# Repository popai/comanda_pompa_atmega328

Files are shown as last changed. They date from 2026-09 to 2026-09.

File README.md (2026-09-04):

# comanda_pompa — controler de umplere bazin

Firmware pentru o placă custom cu **ATmega328PU la 16 MHz** care umple automat un
bazin: comandă releul unei pompe în funcție de nivelul citit cu un senzor
ultrasonic pe RS485 și afișează gradul de umplere pe un bargraph de 7 LED-uri.

Senzorul (**A0121A4**, Modbus RTU) este montat deasupra bazinului și privește în
jos, deci distanța măsurată **scade** pe măsură ce bazinul se umple.

## Logica de funcționare

| Condiție | Acțiune |
|---|---|
| Nivel ≤ 50% (bazin gol sau sub jumătate) | Pornește pompa |
| Nivel ≥ 95% (bazin plin) | Oprește pompa |
| Între 50% și 95% | Păstrează starea curentă |

Banda 50%…95% **este** histerezisul: odată pornită, pompa merge până la plin,
deci nu poate clipi în jurul niciunui prag. Peste asta, un filtru median pe 3
citiri și confirmarea pe 3 citiri consecutive împiedică o singură valoare
aberantă (val, reflexie parazită) să comande releul.

### Protecții

- **Timp maxim de umplere** — 5 de minute de funcționare continuă fără să se
  atingă „plin" înseamnă puț secat, vană închisă sau senzor blocat pe o valoare.
  Pompa se oprește și intră în `AVARIE_TIMP`, stare **cu reținere**: iese doar la
  reset, pentru că repornirea automată ar ține pompa în gol la nesfârșit.
- **Senzor defect** — 5 citiri eșuate consecutive (fără răspuns, CRC greșit, în
  afara plajei) opresc pompa preventiv și trec în `AVARIE_SENZOR`. Starea se
  auto-repară după 3 citiri valide consecutive.
- Releul **nu pornește niciodată** pe baza unei citiri invalide.
- La reset pinul releului este scris `LOW` înainte de `pinMode(OUTPUT)`, ca
  pompa să nu pornească pentru câteva microsecunde la fiecare repornire.
- Watchdog de 8 s, resetat **doar la încheierea unui ciclu de măsurare**, nu la
  fiecare trecere prin `loop()`. Astfel el nu cere doar ca procesorul să fie viu,
  ci ca măsurătorile să avanseze efectiv: dacă bucla s-ar învârti fără să mai
  măsoare (de exemplu cu `millis()` înghețat), watchdog-ul resetează placa și
  pompa se oprește.

## Hardware

### Pinout

| Funcție | Port AVR | Pin Arduino |
|---|---|---|
| LED 1 | PC3 | A3 |
| LED 2 | PC2 | A2 |
| LED 3 | PB5 | 13 |
| LED 4 | PB4 | 12 |
| LED 5 | PB3 | 11 |
| LED 6 | PB2 | 10 |
| LED 7 | PB1 | 9 |
| Releu pompă (activ **HIGH**) | PC4 | A4 |
| RS485 DE + /RE (legate împreună) | PC5 | A5 |
| RS485 RO → RX software | PD5 | 5 |
| RS485 DI ← TX software | PD6 | 6 |

D0/D1 rămân libere pentru upload și pentru logul de debug.
PC4/PC5 sunt și SDA/SCL, dar proiectul nu folosește I2C — fără conflict.

### Senzorul

MAX485 în half-duplex: `DE` și `/RE` sunt legate la același pin, `HIGH` = emisie,
`LOW` = recepție. Firmware-ul ridică linia doar cât durează interogarea.

Comunicația se face pe `SoftwareSerial` la 9600 8N1, protocol Modbus RTU:

- comandă: `01 03 01 01 00 01 D4 36`
- răspuns: 7 octeți — `adresă, funcție, lungime, dataHi, dataLo, crcLo, crcHi`
- valoarea este în zecimi de milimetru; `(dataHi * 256 + dataLo) / 10` = cm
- `dataHi == 0xFF` înseamnă „în afara plajei"

Protocolul, CRC-ul și filtrul de sincronizare sunt preluate neschimbat din
implementarea Zephyr validată pe hardware
(`ncs_app/senzor_umplere/src/dist_sensor.c`). Filtrul aruncă octeți până
întâlnește `0x01` urmat de `0x03`, ceea ce este necesar pentru că la alimentare
senzorul emite un banner text (`APP Run...`) lung exact cât un cadru Modbus.

## Calibrare

**Obligatoriu la montaj.** În [`include/config.h`](include/config.h):

```c
static const uint16_t DIST_PLIN_CM = 20;   // senzor -> suprafața apei, bazin plin
static const uint16_t DIST_GOL_CM  = 150;  // senzor -> fundul bazinului
```

Procedura: montează placa pe bazin, deschide monitorul serial, citește distanța
raportată cu bazinul gol și cu bazinul plin, pune cele două valori aici și
recompilează. Nivelul se calculează liniar între ele, saturat la 0 și 100%.

Restul parametrilor reglabili — praguri, numărul de confirmări, timeout-uri,
timpul maxim de umplere — sunt tot acolo. `config.h` este singurul fișier care
trebuie atins pentru reglaje; în restul codului nu există numere magice.

## Indicații pe LED-uri

**Funcționare normală** — bargraph, LED-urile 1..7 de la nivel mic la nivel mare.
Pragurile sunt așezate la mijlocul fiecărei trepte (≈7, 21, 35, 50, 64, 78, 92%),
cu o zonă moartă de ±2%, ca LED-ul de vârf să nu pâlpâie când nivelul stă exact
pe un prag. Un bazin aproape gol arată „un LED", nu zero — asta distinge vizual
nivelul mic de afișajul stins.

**Avarie** — două tipare imposibil de confundat cu un bargraph real:

| Tipar | Semnificație |
|---|---|
| Toate 7 clipind sincron, 2 Hz | `AVARIE_SENZOR` — senzorul nu răspunde |
| Alternanță 1-3-5-7 / 2-4-6, 1 Hz | `AVARIE_TIMP` — timp maxim depășit, cere reset |

## Compilare și încărcare

Proiect [PlatformIO](https://platformio.org/), env `uno` (ATmega328P la 16 MHz,
bootloader Arduino):

```sh
pio run                 # compilare
pio run -t upload       # încărcare
pio device monitor      # log de debug, 115200 baud
```

Binarul rezultă la `.pio/build/uno/comanda_pompa_uno.hex` — numele este compus
din numele proiectului și al plăcii de către [`extra_script.py`](extra_script.py).

### Ieșirea pe serial

Câte o linie la fiecare ciclu de măsurare (1 s):

```
=== Controler umplere bazin ===
Plin la 20 cm, gol la 150 cm; pornire sub 50%, oprire peste 95%
98 cm | 40% | OPRITA
97 cm | 40% | OPRITA
96 cm | 41% | PORNITA
--- | senzor: fara raspuns | PORNITA
```

## Structura codului

| Fișier | Rol |
|---|---|
| [`include/config.h`](include/config.h) | Pini, cotele bazinului, praguri, timpi — singurul loc de reglat |
| [`src/dist_sensor.cpp`](src/dist_sensor.cpp) | Driver Modbus RTU pe RS485: CRC, sincronizare cadru, reîncercări |
| [`src/pump.cpp`](src/pump.cpp) | Mașina de stări, filtrul median, comanda releului |
| [`src/leds.cpp`](src/leds.cpp) | Bargraph cu histerezis și tiparele de avarie |
| [`src/main.cpp`](src/main.cpp) | `setup()`/`loop()`, watchdog, conversia distanță → procent |

Bucla principală este non-blocantă (`millis()`, fără `delay()`), cu excepția
ciclului de măsurare: cel mult 3 × 550 ms, iar în cazul bun răspunsul vine în
~100 ms.

## Punere în funcțiune

1. `pio run` — compilare curată, fără warning-uri.
2. Alimentează placa **fără senzor conectat** și urmărește monitorul: după 5
   citiri eșuate trebuie să intre în `AVARIE_SENZOR`, cu releul oprit și toate
   LED-urile clipind. Confirmă protecția de senzor defect.
3. Conectează senzorul pe masă, apropie și depărtează o placă plană și verifică
   în log că distanța corespunde realității și că bargraph-ul urcă și coboară.
4. Verifică tranzițiile: releul anclanșează sub 50%, declanșează la 95% și **nu**
   comută între aceste valori.
5. Pentru testul de timp maxim, coboară temporar `MAX_TIMP_UMPLERE_MS` la 30 s,
   ține nivelul sub 50% și confirmă trecerea în `AVARIE_TIMP`.
6. Montează pe bazin, calibrează cele două cote și urmărește un ciclu complet de
   umplere.

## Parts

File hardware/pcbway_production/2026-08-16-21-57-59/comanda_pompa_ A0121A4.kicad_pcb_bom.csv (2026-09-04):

Designator | Quantity | Value | Footprint | Package | MPN | DNP | Mount_Type | Description | KiLib_Generator | LCSC Part # | Manufacturer Mfr. Part # | Sim.Device | Sim.Pins
C1 | 1 | 100nF/C0603 | C_Disc_D3.0mm_W1.6mm_P2.50mm |  |  |  | tht | Unpolarized capacitor, small symbol | capacitor/THT/other | C30926 | 0603B104K500NT
C2, C3 | 2 | 22pF | C_Disc_D3.0mm_W1.6mm_P2.50mm |  |  |  | tht | Unpolarized capacitor, small symbol | capacitor/THT/other
D10 | 1 | RB151 | Diode_Bridge_Round_D9.0mm |  |  |  | tht | Single-Phase Bridge Rectifier, 35V Vrms, 1.5A If, WOG-like package
D2 | 1 | 1N4148 | D_A-405_P10.16mm_Horizontal |  |  |  | tht | Diode, small symbol | diode/THT |  |  | D | 1=K 2=A
J10 | 1 | RS485_M | PinHeader_1x04_P2.54mm_Vertical |  |  |  | tht | Generic connector, single row, 01x04, script generated (kicad-library-utils/schlib/autogen/connector/) | connector/pin_header_socket
J11, J5 | 2 | NC (test led) | PinHeader_1x01_P2.54mm_Vertical |  |  |  | tht | Generic connector, single row, 01x01, script generated | connector/pin_header_socket
J2 | 1 | 220V IN | PhoenixContact_GMSTBA_2,5_6-G-7,62_1x06_P7.62mm_Horizontal |  |  |  | tht | Generic connector, single row, 01x06, script generated (kicad-library-utils/schlib/autogen/connector/) | connector/PhoenixContact
J6 | 1 | CONSOLA | PinHeader_1x04_P2.54mm_Vertical |  |  |  | tht | Generic connector, single row, 01x04, script generated (kicad-library-utils/schlib/autogen/connector/) | connector/pin_header_socket | C2883761 | X6511WVS-04H-C60D48R2
J7 | 1 | LEDS | PinHeader_1x08_P2.54mm_Vertical |  |  |  | tht | Generic connector, single row, 01x08, script generated (kicad-library-utils/schlib/autogen/connector/) | connector/pin_header_socket
J8 | 1 | LED | PinHeader_1x03_P2.54mm_Vertical |  |  |  | tht | Generic connector, single row, 01x03, script generated (kicad-library-utils/schlib/autogen/connector/) | connector/pin_header_socket
J9 | 1 | RS485_uC | PinHeader_1x04_P2.54mm_Vertical |  |  |  | tht | Generic connector, single row, 01x04, script generated (kicad-library-utils/schlib/autogen/connector/) | connector/pin_header_socket
Q2 | 1 | BD139 | TO-126-3_Vertical |  |  |  | tht | 1.5A Ic, 80V Vce, Low Voltage Transistor, TO-126 | package/TO_SOT/THT |  |  | NPN | 1=E 2=C 3=B
R10, R11, R12, R3, R6, R7, R8, R9 | 8 | 1K | R_Axial_DIN0207_L6.3mm_D2.5mm_P10.16mm_Horizontal |  |  |  | tht | Resistor, small symbol | resistor/THT
R13, R4 | 2 | 360R | R_Axial_DIN0207_L6.3mm_D2.5mm_P10.16mm_Horizontal |  |  |  | tht | Resistor, small symbol | resistor/THT
R14, R15, R5 | 3 | 10K | R_Axial_DIN0207_L6.3mm_D2.5mm_P10.16mm_Horizontal |  |  |  | tht | Resistor, small symbol | resistor/THT
R2 | 1 | 1k | R_Axial_DIN0207_L6.3mm_D2.5mm_P7.62mm_Horizontal |  |  |  | tht | Resistor | resistor/THT
RL1 | 1 | 891WP-1A-C | 891WP-1A-C |  |  |  | tht | Standex Meder UMS reed relay, SPST, Closing Contact
SENZOR_D1 | 1 | SENZOR_D | PinHeader_1x04_P2.54mm_Vertical |  |  |  | tht | Generic connector, single row, 01x04, script generated (kicad-library-utils/schlib/autogen/connector/) | connector/pin_header_socket
T1 | 1 | Transformer_1P_1S | Trafo_10V |  |  |  | tht | Transformer, single primary, single secondary
U1 | 1 | ATmega328P-P | DIP-28_W7.62mm |  |  |  | tht | 20MHz, 32kB Flash, 2kB SRAM, 1kB EEPROM, DIP-28 | package/DIP/legacy
U2 | 1 | XL4016_ADJ | Sursa_adj_5V |  |  |  | tht
U3 | 1 | 4N25 | DIP-6_W7.62mm |  |  |  | tht | DC Optocoupler Base Connected, Vce 30V, CTR 20%, Viso 2500V, DIP6 | package/DIP/legacy
U4 | 1 | ULN2003 | DIP-16_W7.62mm_LongPads |  |  |  | tht | High Voltage, High Current Darlington Transistor Arrays, SOIC16/SOIC16W/DIP16/TSSOP16 | package/DIP/legacy
Y1 | 1 | 16MHz | Crystal_HC49-4H_Vertical |  |  |  | tht | Two pin crystal, small symbol | crystal_resonator_oscillator

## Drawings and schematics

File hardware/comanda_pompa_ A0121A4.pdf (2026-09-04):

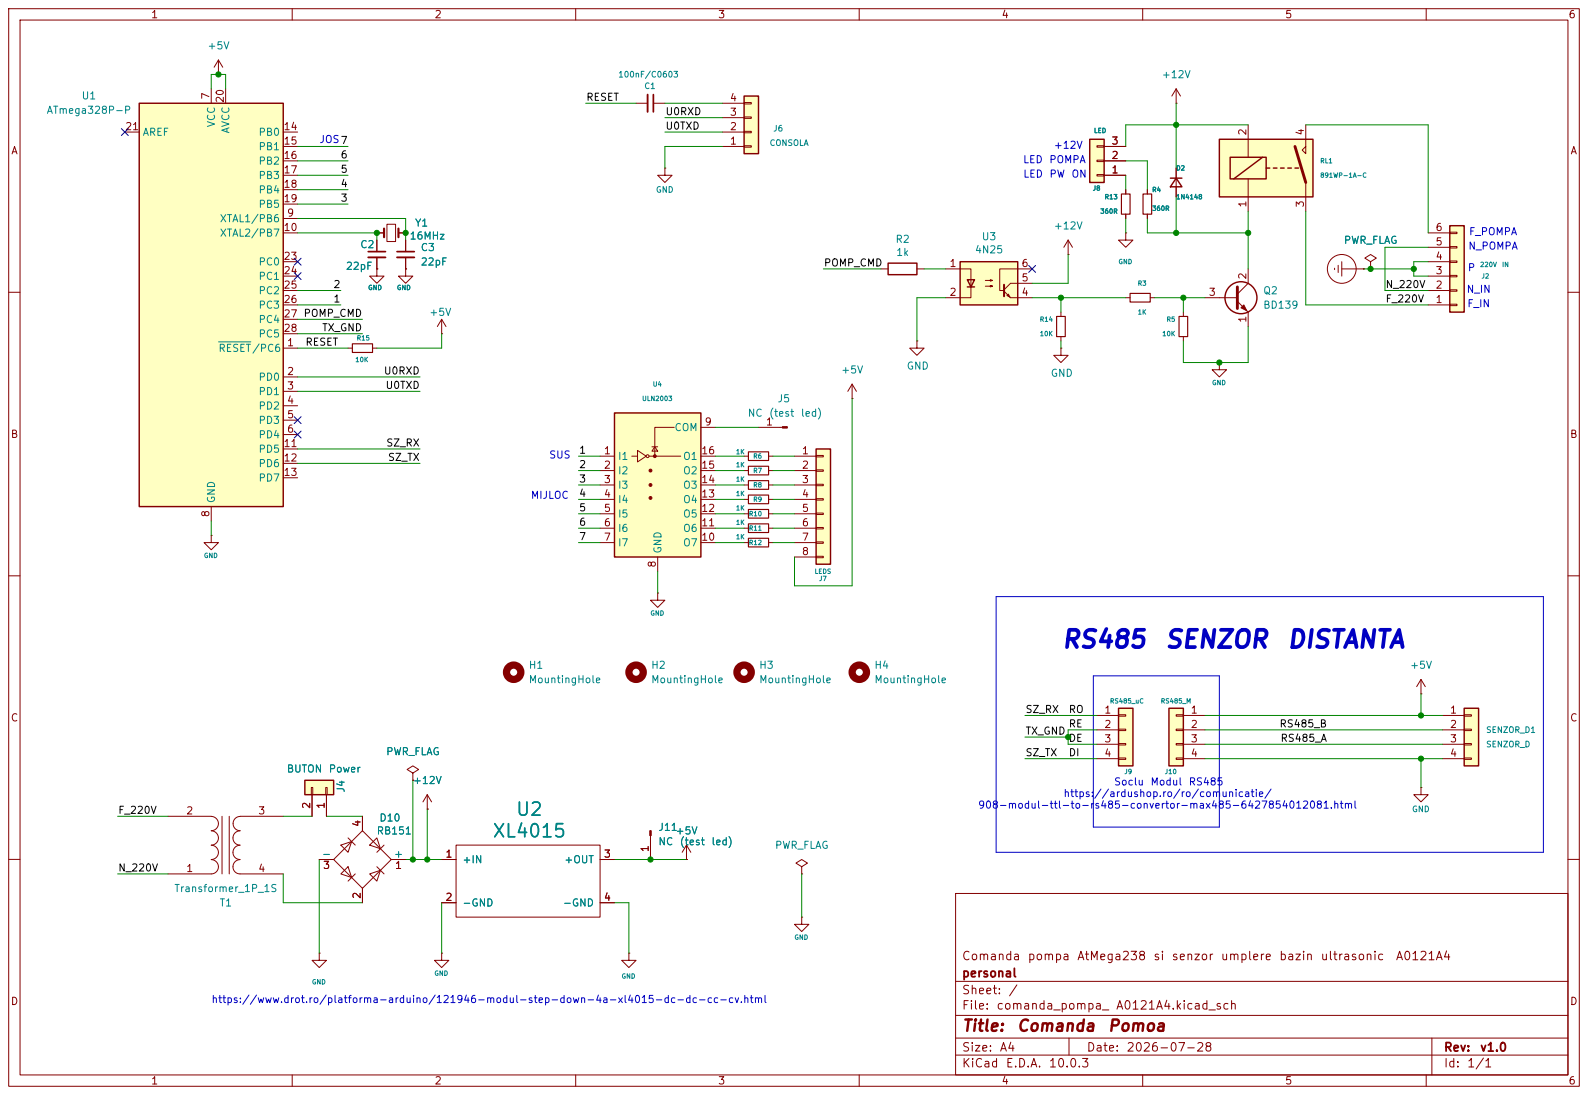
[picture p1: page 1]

908-modul-ttl-to-rs485-convertor-max485-6427854012081.html MIJLOC

https://ardushop.ro/ro/comunicatie/

Comanda pompa AtMega238 si senzor umplere bazin ultrasonic A0121A4
personal
Sheet: /
File: comanda_pompa_ A0121A4.kicad_sch
Title: Comanda Pomoa

https://www.drot.ro/platforma-arduino/121946-modul-step-down-4a-xl4015-dc-dc-cc-cv.html

Size: A4 | Rev: v1.0
KiCad E.D.A. 10.0.3 | Id: 1/1

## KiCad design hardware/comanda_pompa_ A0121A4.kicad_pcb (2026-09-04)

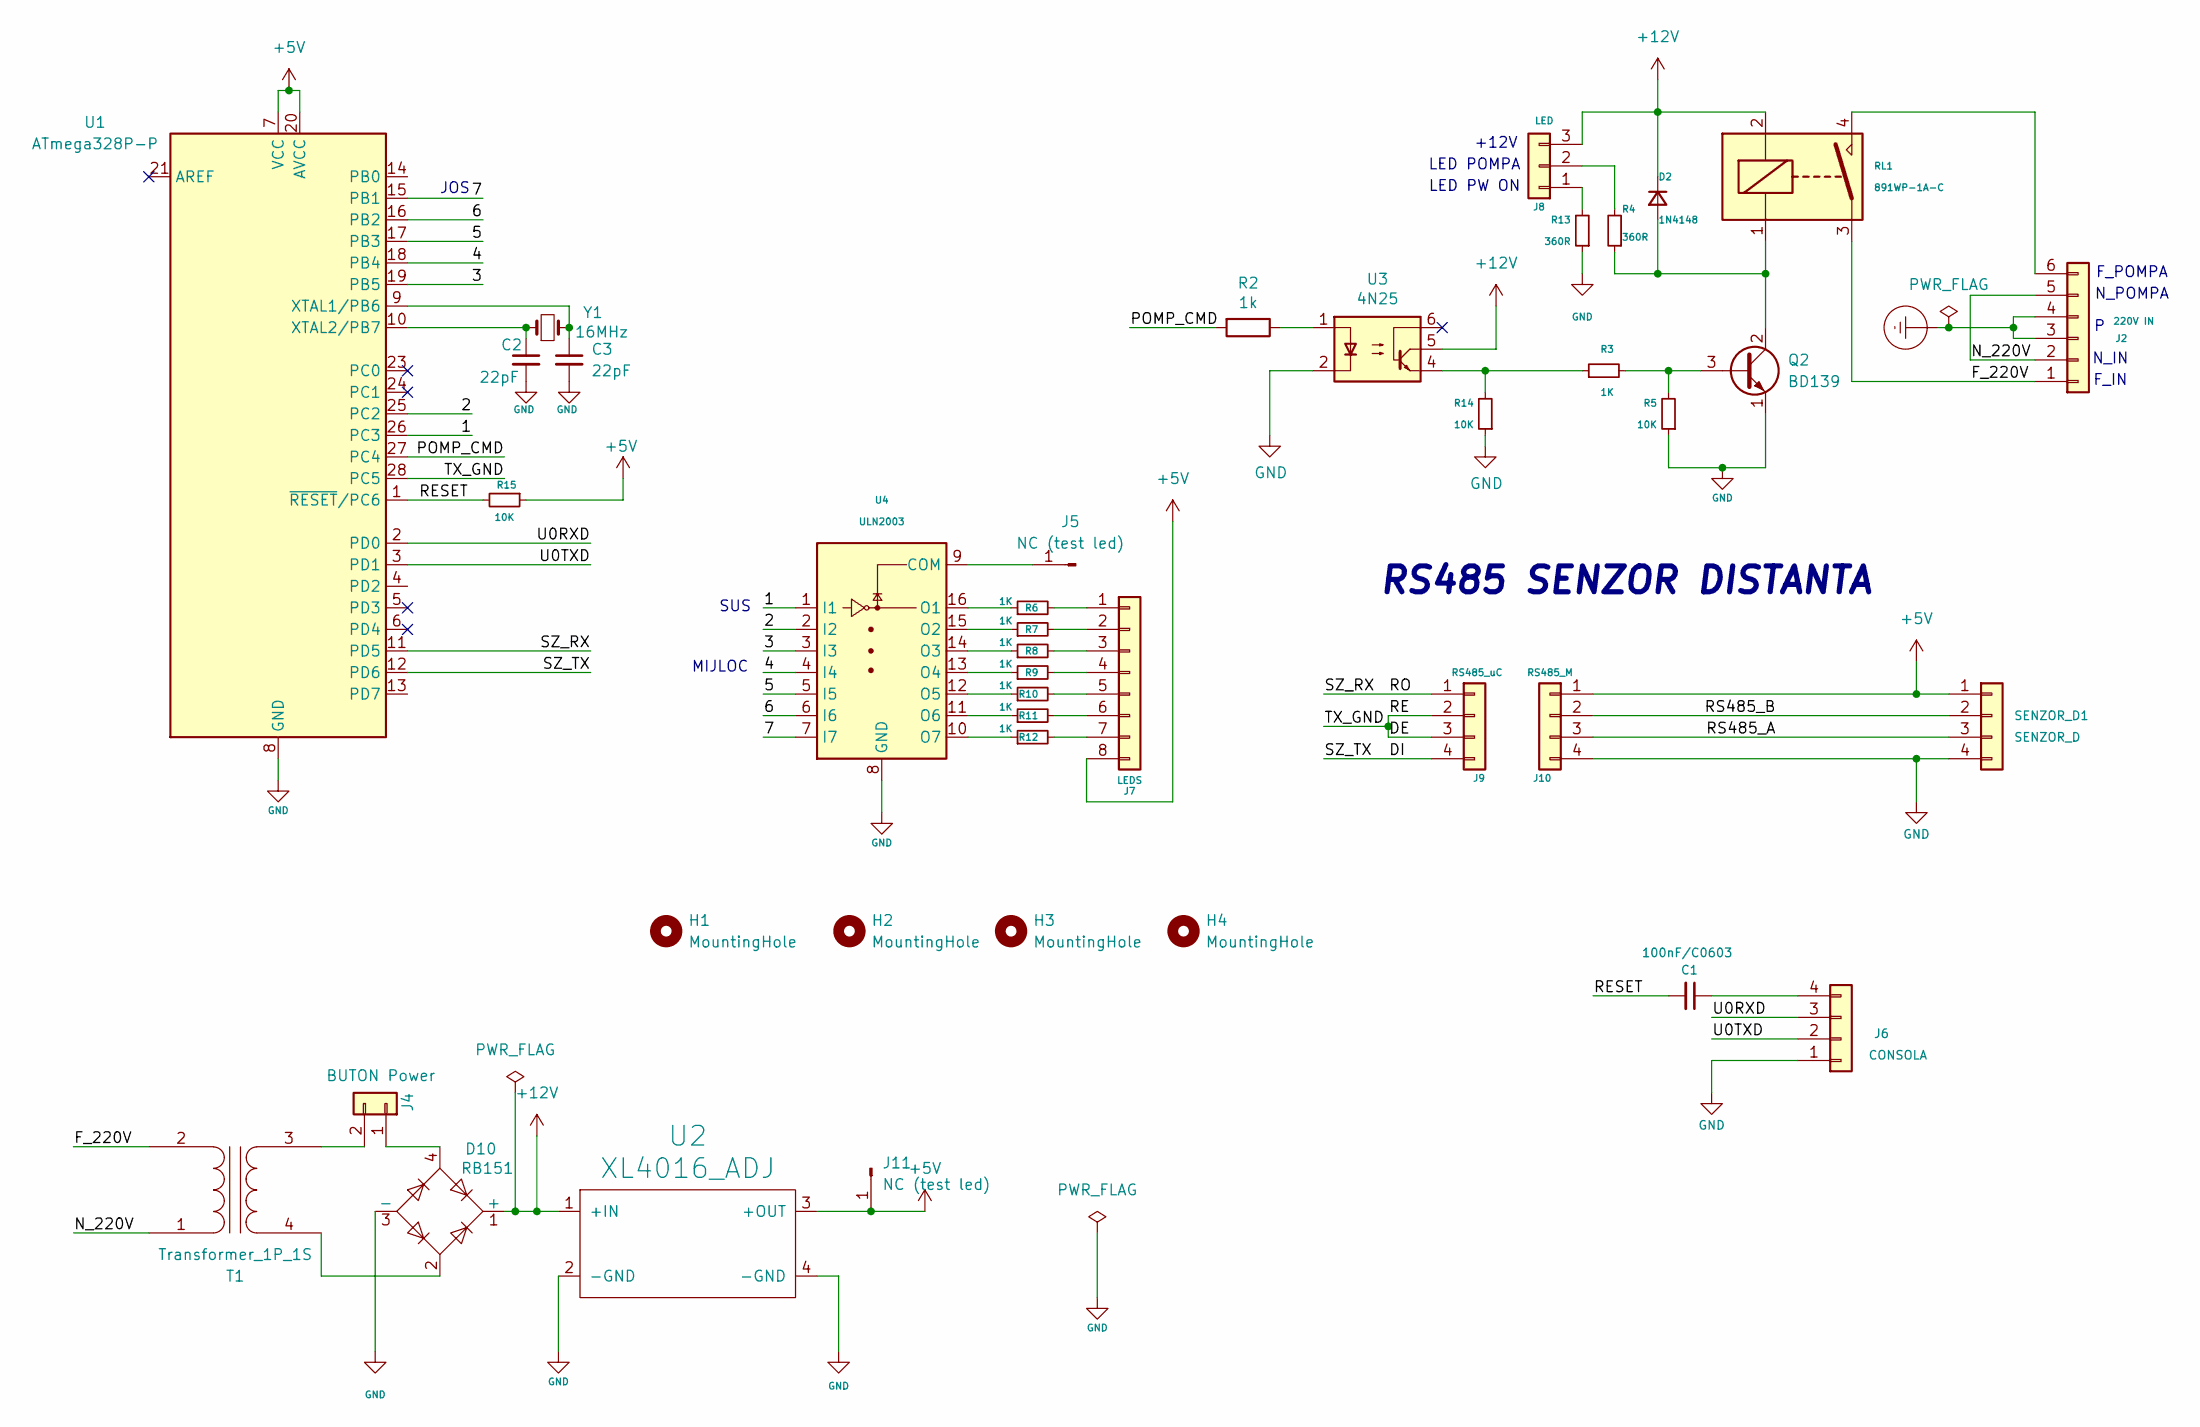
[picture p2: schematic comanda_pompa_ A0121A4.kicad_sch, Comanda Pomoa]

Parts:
C1: 100nF/C0603; C_Disc_D3.0mm_W1.6mm_P2.50mm; LCSC Part # C30926
C2, C3: 22pF; C_Disc_D3.0mm_W1.6mm_P2.50mm
D2: 1N4148; D_A-405_P10.16mm_Horizontal
D10: RB151; Diode_Bridge_Round_D9.0mm
H1, H2, H3, H4: MountingHole; MountingHole_3.2mm_M3
J2: 220V IN; PhoenixContact_GMSTBA_2,5_6-G-7,62_1x06_P7.62mm_Horizontal
J4: BUTON Power; PhoenixContact_MCV_1,5_2-G-3.5_1x02_P3.50mm_Vertical; LCSC Part # C144394
J5, J11: NC (test led); PinHeader_1x01_P2.54mm_Vertical
J6: CONSOLA; PinHeader_1x04_P2.54mm_Vertical; LCSC Part # C2883761
J7: LEDS; PinHeader_1x08_P2.54mm_Vertical
J8: LED; PinHeader_1x03_P2.54mm_Vertical
J9: RS485_uC; PinSocket_1x04_P2.54mm_Vertical
J10: RS485_M; PinSocket_1x04_P2.54mm_Vertical
Q2: BD139; TO-126-3_Vertical
R2: 1k; R_Axial_DIN0207_L6.3mm_D2.5mm_P7.62mm_Horizontal
R3, R6, R7, R8, R9, R10, R11, R12: 1K; R_Axial_DIN0207_L6.3mm_D2.5mm_P10.16mm_Horizontal
R4, R13: 360R; R_Axial_DIN0207_L6.3mm_D2.5mm_P10.16mm_Horizontal
R5, R14, R15: 10K; R_Axial_DIN0207_L6.3mm_D2.5mm_P10.16mm_Horizontal
RL1: 891WP-1A-C
SENZOR_D1: SENZOR_D; PinHeader_1x04_P2.54mm_Vertical
T1: Transformer_1P_1S; Trafo_10V
U1: ATmega328P-P; DIP-28_W7.62mm
U2: XL4016_ADJ; Sursa_adj_5V
U3: 4N25; DIP-6_W7.62mm
U4: ULN2003; DIP-16_W7.62mm_LongPads
Y1: 16MHz; Crystal_HC49-4H_Vertical

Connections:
+5V: J7.8, J10.1, J11.1 (Pin_1_1), R15.1, SENZOR_D1.1, U1.7 (VCC), U1.20 (AVCC), U2.3 (+OUT)
+12V: D2.1 (K), D10.1 (+), J8.3, RL1.2, U2.1 (+IN), U3.5
/1: U1.26 (PC3), U4.1 (I1)
/2: U1.25 (PC2), U4.2 (I2)
/3: U1.19 (PB5), U4.3 (I3)
/4: U1.18 (PB4), U4.4 (I4)
/5: U1.17 (PB3), U4.5 (I5)
/6: U1.16 (PB2), U4.6 (I6)
/7: U1.15 (PB1), U4.7 (I7)
/DE: J9.2, J9.3, U1.28 (PC5)
/DI: J9.4, U1.12 (PD6)
/F_220V: J2.1, RL1.3, T1.2 (AB)
/N_220V: J2.2, J2.5, T1.1 (AA)
/POMP_CMD: R2.2, U1.27 (PC4)
/RESET: C1.2, R15.2, U1.1 (~RESET/PC6)
/RO: J9.1, U1.11 (PD5)
/RS485_A: J10.3, SENZOR_D1.3
/RS485_B: J10.2, SENZOR_D1.2
/U0RXD: J6.3, U1.2 (PD0)
/U0TXD: J6.2, U1.3 (PD1)
Earth_Protective: J2.3, J2.4
GND: C2.2, C3.2, D10.3 (-), J6.1, J10.4, Q2.1 (E), R5.1, R13.1, R14.1, SENZOR_D1.4, U1.8 (GND), U1.22 (GND), U2.2 (-GND), U2.4 (-GND), U3.2, U4.8 (GND)
unnamed: D2.2 (A), Q2.2 (C), R4.1, RL1.1
unnamed: J2.6, RL1.4
unnamed: D10.4, J4.1
unnamed: J4.2, T1.3 (SA)
unnamed: J5.1 (Pin_1_1), U4.9 (COM)
unnamed: C1.1, J6.4
unnamed: J7.1, R6.2
unnamed: J7.2, R7.2
unnamed: J7.3, R8.2
unnamed: J7.4, R9.2
unnamed: J7.5, R10.2
unnamed: J7.6, R11.2
unnamed: J7.7, R12.2
unnamed: J8.1, R13.2
unnamed: J8.2, R4.2
unnamed: Q2.3 (B), R3.2, R5.2
unnamed: R2.1, U3.1
unnamed: R3.1, R14.2, U3.4
unnamed: D10.2, T1.4 (SB)
unnamed: C3.1, U1.9 (XTAL1/PB6), Y1.2
unnamed: C2.1, U1.10 (XTAL2/PB7), Y1.1
unnamed: R6.1, U4.16 (O1)
unnamed: R7.1, U4.15 (O2)
unnamed: R8.1, U4.14 (O3)
unnamed: R9.1, U4.13 (O4)
unnamed: R10.1, U4.12 (O5)
unnamed: R11.1, U4.11 (O6)
unnamed: R12.1, U4.10 (O7)

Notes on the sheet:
JOS
MIJLOC
F_POMPA
N_IN
+12V
SUS
N_POMPA
RS485 SENZOR DISTANTA
LED PW ON
LED POMPA
F_IN

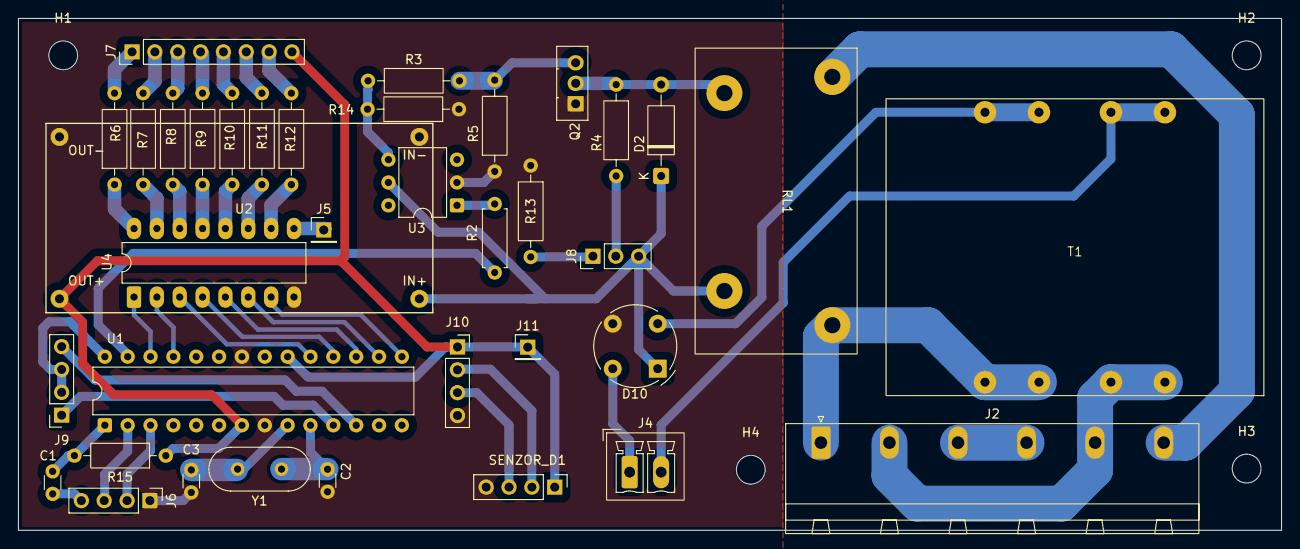
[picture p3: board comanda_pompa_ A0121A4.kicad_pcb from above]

Board: 2 copper layers, 140.4 x 56.9 mm, 41 parts (0 on the bottom side), 50 nets.

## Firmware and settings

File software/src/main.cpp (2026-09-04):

/*
 * Copyright (c) 2026 Popa Ionel, TWM
 *
 * SPDX-License-Identifier: Apache-2.0
 *
 * Controler de umplere bazin pe ATmega328PU (16 MHz):
 *   - senzor ultrasonic A0121A4 pe RS485/Modbus RTU, montat deasupra bazinului;
 *   - releu de pompa, activ pe HIGH;
 *   - bargraph de 7 LED-uri pentru nivel.
 *
 * Logica: sub jumatate porneste pompa, plin o opreste. Peste asta, trei
 * protectii: histerezis, timp maxim de umplere si oprire la senzor defect.
 */

#include <Arduino.h>
#include <avr/wdt.h>

#include "config.h"
#include "dist_sensor.h"
#include "leds.h"
#include "pump.h"

static uint32_t t_ultima_masuratoare;

/**
 * @brief Converteste distanta masurata in grad de umplere.
 *
 * Senzorul priveste in jos, deci distanta scade cand bazinul se umple.
 * Saturarea la 0 si 100 acopera si cazurile in care apa depaseste cota "plin"
 * sau senzorul vede dincolo de cota "gol".
 */
static uint8_t dist_la_procent(uint16_t cm)
{
	if (cm <= DIST_PLIN_CM)
	{
		return 100;
	}
	if (cm >= DIST_GOL_CM)
	{
		return 0;
	}

	return (uint8_t)(((uint32_t)(DIST_GOL_CM - cm) * 100UL) /
					 (uint32_t)(DIST_GOL_CM - DIST_PLIN_CM));
}

void setup()
{
	/* Releul primul: intre reset si aici pinul este intrare, deci pompa e
	 * oprita; pump_init() o tine oprita si dupa ce pinul devine iesire.
	 */
	pump_init();
	leds_init();

	Serial.begin(SERIAL_BAUD);
	Serial.println();
	Serial.println(F("=== Controler umplere bazin ==="));
	Serial.print(F("Plin la "));
	Serial.print(DIST_PLIN_CM);
	Serial.print(F(" cm, gol la "));
	Serial.print(DIST_GOL_CM);
	Serial.print(F(" cm; pornire sub "));
	Serial.print(PRAG_PORNIRE_PCT);
	Serial.print(F("%, oprire peste "));
	Serial.print(PRAG_OPRIRE_PCT);
	Serial.println(F("%"));

	dist_sensor_init();

	/* Senzorul isi emite bannerul de pornire si ignora interogarile pana la
	 * ~1 s de la alimentare. Aici inca nu are ce reseta watchdog-ul, deci
	 * asteptarea se face inaintea activarii lui.
	 */
	delay(WARMUP_MS);

	/* Un ciclu de masurare dureaza cel mult DIST_RETRIES * DIST_TIMEOUT_MS
	 * (~1,7 s), deci 8 s lasa marja larga. Bootloader-ul optiboot al placii
	 * trateaza corect resetul de watchdog.
	 */
	wdt_enable(WDTO_8S);

	/* Prima masuratoare imediat, nu dupa un interval. */
	t_ultima_masuratoare = millis() - INTERVAL_MASURARE_MS;
}

void loop()
{
	leds_tick();

	if (millis() - t_ultima_masuratoare < INTERVAL_MASURARE_MS)
	{
		return;
	}
	t_ultima_masuratoare = millis();

	/* Ultimul nivel valid: la o citire esuata bargraph-ul il pastreaza, in loc
	 * sa cada la zero si sa sugereze un bazin gol care nu exista. Daca
	 * esecurile continua, pump_update() intra oricum in AVARIE_SENZOR si
	 * afisajul trece pe tiparul de eroare.
	 */
	static uint8_t ultimul_nivel;

	uint16_t cm = 0;
	enum dist_status st = dist_sensor_measure(&cm);
	bool valid = (st == DIST_OK);
	uint8_t nivel = valid ? dist_la_procent(cm) : ultimul_nivel;

	if (valid)
	{
		ultimul_nivel = nivel;
	}

	pump_update(nivel, valid);
	leds_set(nivel, pump_get_state());

	/* Watchdog-ul se reseteaza abia aici, nu la intrarea in loop().
	 *
	 * loop() este reapelata imediat de main()-ul Arduino, deci un reset pus
	 * inaintea iesirii premature de mai sus l-ar mangaia de mii de ori pe
	 * secunda si ar transforma watchdog-ul intr-un simplu detector de blocaj
	 * al procesorului. Daca insa millis() ingheata - intreruperi ramase
	 * dezactivate - bucla s-ar invarti la nesfarsit fara sa mai masoare, iar
	 * pompa ar ramane pornita definitiv: exact ce trebuie sa prinda watchdog-ul.
	 *
	 * Resetat aici, el cere dovada ca un ciclu complet s-a incheiat. In cel mai
	 * rau caz intre doua resetari trec INTERVAL_MASURARE_MS plus durata maxima
	 * a masuratorii (DIST_RETRIES * DIST_TIMEOUT_MS), adica ~2,7 s - confortabil
	 * sub cele 8 s ale watchdog-ului.
	 */
	wdt_reset();

	if (valid)
	{
		Serial.print(cm);
		Serial.print(F(" cm | "));
		Serial.print(nivel);
		Serial.print(F("% | "));
	}
	else
	{
		Serial.print(F("--- | senzor: "));
		Serial.print(dist_status_detail(st));
		Serial.print(F(" | "));
	}
	Serial.println(pump_state_str(pump_get_state()));
}

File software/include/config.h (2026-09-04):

/*
 * Copyright (c) 2026 Popa Ionel, TWM
 *
 * SPDX-License-Identifier: Apache-2.0
 *
 * @brief Singurul loc de reglat: pini, cotele bazinului, praguri, timpi.
 */

#ifndef CONFIG_H_
#define CONFIG_H_

#include <Arduino.h>

/* ------------------------------------------------------------------ Pini ---
 *
 * Maparea urmeaza cablajul placii custom (ATmega328PU, 16 MHz). In paranteza
 * portul AVR, ca sa poata fi verificata direct pe schema.
 */

/* LED 1..7, de la nivelul cel mai mic la cel mai mare. */
static const uint8_t LED_PINS[] = {
	A3, /* PC3 - LED 1 */
	A2, /* PC2 - LED 2 */
	13, /* PB5 - LED 3 */
	12, /* PB4 - LED 4 */
	11, /* PB3 - LED 5 */
	10, /* PB2 - LED 6 */
	9,	/* PB1 - LED 7 */
};

#define LED_COUNT ((uint8_t)(sizeof(LED_PINS) / sizeof(LED_PINS[0])))

/* Releul pompei. Activ pe HIGH: la reset pinul este intrare cu pull-up dezactivat,
 * deci releul ramane declansat pana cand setup() decide altfel.
 */
static const uint8_t PIN_RELEU = A4; /* PC4 */
static const uint8_t RELEU_ACTIV = HIGH;
static const uint8_t RELEU_INACTIV = LOW;

/* RS485: DE si /RE sunt legate impreuna pe acelasi pin - HIGH = emisie,
 * LOW = receptie.
 */
static const uint8_t PIN_RS485_DE = A5; /* PC5 */
static const uint8_t PIN_RS485_RX = 5;	/* PD5 <- RO */
static const uint8_t PIN_RS485_TX = 6;	/* PD6 -> DI */

/* -------------------------------------------------- Geometria bazinului ---
 *
 * DE CALIBRAT LA MONTAJ. Senzorul priveste in jos, deci distanta scade pe
 * masura ce bazinul se umple.
 */

/** Distanta senzor -> suprafata apei cu bazinul plin (cm). */
static const uint16_t DIST_PLIN_CM = 20;

/** Distanta senzor -> fundul bazinului, adica bazin gol (cm). */
static const uint16_t DIST_GOL_CM = 150;

/* ------------------------------------------------------ Praguri pompa ---- */

/** Sub acest nivel pompa porneste ("mai putin de jumatate plin"). */
static const uint8_t PRAG_PORNIRE_PCT = 50;

/** Peste acest nivel pompa se opreste ("plin").
 *
 * 95 si nu 100: ultimii centimetri intra in zona oarba a senzorului, iar
 * valurile facute chiar de jetul pompei fac citirea instabila acolo.
 */
static const uint8_t PRAG_OPRIRE_PCT = 95;

/** Citiri valide consecutive care confirma o tranzitie de stare.
 *
 * Impreuna cu filtrul median, impiedica o singura citire aberanta sa comande
 * releul.
 */
static const uint8_t CONFIRMARI_SCHIMBARE = 3;

/* --------------------------------------------------------------- Senzor ---
 *
 * Valorile de plaja sunt aceleasi ca in implementarea Zephyr validata pe
 * hardware (senzor_umplere/src/dist_sensor.c).
 */

static const uint16_t DIST_MIN_CM = 2;
static const uint16_t DIST_MAX_CM = 400;

/** Reincercari per masuratoare. */
static const uint8_t DIST_RETRIES = 3;

/** Timp de asteptare a cadrului complet, per incercare (ms). */
static const uint16_t DIST_TIMEOUT_MS = 550;

/** Perioada ciclului de masurare (ms). */
static const uint16_t INTERVAL_MASURARE_MS = 1000;

/** Pauza la pornire, inainte de prima interogare (ms).
 *
 * La alimentare senzorul isi emite bannerul text de start si ignora
 * interogarile. Masurat pe hardware: la ~509 ms inca nu raspunde, la ~1077 ms
 * raspunde corect.
 */
static const uint16_t WARMUP_MS = 1500;

/* ------------------------------------------------------------ Protectii ---*/

/** Citiri esuate consecutive dupa care pompa se opreste preventiv. */
static const uint8_t MAX_ESECURI_SENZOR = 5;

/** Citiri valide consecutive care sting avaria de senzor. */
static const uint8_t CONFIRMARI_REVENIRE = 3;

/** Timp maxim de functionare continua a pompei (ms).
 *
 * Depasirea inseamna ca nivelul nu creste desi pompa merge: put secat, vana
 * inchisa sau senzor blocat pe o valoare. Avaria este cu retinere (latch) -
 * iese doar la reset - pentru ca repornirea automata ar arde pompa in gol.
 */
static const uint32_t MAX_TIMP_UMPLERE_MS = 5UL * 60UL * 1000UL;

/* ------------------------------------------------------------------ LED ---*/

/** Zona moarta la pragurile bargraph-ului (puncte procentuale). */
static const uint8_t LED_HIST_PCT = 2;

/** Semiperioada clipirii la avarie de senzor (ms) - 2 Hz. */
static const uint16_t LED_BLINK_SENZOR_MS = 250;

/** Semiperioada alternantei la avarie de timp (ms) - 1 Hz. */
static const uint16_t LED_BLINK_TIMP_MS = 500;

/* ---------------------------------------------------------------- Debug ---*/

/** Viteza portului serial de log (D0/D1, liber pe aceasta placa). */
static const uint32_t SERIAL_BAUD = 115200;

#endif /* CONFIG_H_ */

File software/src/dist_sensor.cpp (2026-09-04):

/*
 * Copyright (c) 2026 Popa Ionel, TWM
 *
 * SPDX-License-Identifier: Apache-2.0
 *
 * Port pe AVR al driverului Modbus din senzor_umplere/src/dist_sensor.c.
 * Protocolul este identic; s-au schimbat doar transportul (SoftwareSerial +
 * MAX485 in loc de UART hardware) si asteptarea cadrului (bucla pe millis() in
 * loc de ISR + semafor, pentru ca SoftwareSerial isi are deja propria receptie
 * pe intreruperi de schimbare de pin).
 */

#include <string.h>

#include <Arduino.h>
#include <SoftwareSerial.h>

#include "config.h"
#include "dist_sensor.h"

/* 1 adresa + 1 functie + 1 lungime + 2 date + 2 CRC */
#define MODBUS_FRAME_LEN 7

/* Adresa de slave si functia asteptate in raspuns, folosite si ca puncte de
 * sincronizare a cadrului.
 */
#define MODBUS_SLAVE_ADDR 0x01
#define MODBUS_FUNC_READ 0x03

/* Citirea registrului de distanta. */
static const uint8_t sz_command[] = {
	0x01, 0x03, 0x01, 0x01, 0x00, 0x01, 0xD4, 0x36};

/* uint8_t, nu char: cadrul este binar, iar 'char' cu semn ar strica atat
 * comparatia cu 0xFF cat si reconstructia CRC-ului.
 */
static uint8_t rx_buf[MODBUS_FRAME_LEN];
static uint8_t rx_buf_pos;

/* Octeti primiti si aruncati de sincronizare. Fara acest contor, "niciun octet
 * primit" nu distinge senzorul mut de senzorul care isi scrie bannerul de start.
 */
static uint16_t rx_ignored;

static SoftwareSerial sz_serial(PIN_RS485_RX, PIN_RS485_TX);

const char *dist_status_detail(enum dist_status st)
{
	switch (st)
	{
	case DIST_OK:
		return "ok";
	case DIST_ERR_NO_REPLY:
		return "fara raspuns";
	case DIST_ERR_CRC:
		return "cadru invalid";
	case DIST_ERR_RANGE:
		return "in afara plajei";
	default:
		return "necunoscut";
	}
}

static uint16_t modrtu_crc(const uint8_t *buf, int len)
{
	uint16_t crc = 0xFFFF;

	for (int pos = 0; pos < len; pos++)
	{
		crc ^= (uint16_t)buf[pos]; /* XOR byte into least sig. byte of crc */

		for (int i = 8; i != 0; i--)
		{ /* Loop over each bit */
			if ((crc & 0x0001) != 0)
			{			   /* If the LSB is set */
				crc >>= 1; /* Shift right and XOR 0xA001 */
				crc ^= 0xA001;
			}
			else
			{
				crc >>= 1; /* Else LSB is not set, just shift right */
			}
		}
	}

	return crc;
}

void dist_sensor_init(void)
{
	/* Receptie implicita: transceiverul nu tine linia ocupata decat cat dureaza
	 * propria interogare.
	 */
	digitalWrite(PIN_RS485_DE, LOW);
	pinMode(PIN_RS485_DE, OUTPUT);

	sz_serial.begin(9600);
	sz_serial.listen();
}

static void request_send(void)
{
	/* Bufferul se goleste imediat inainte de interogare: orice octet ramas de
	 * la bannerul de pornire sau de la incercarea anterioara ar decala cadrul.
	 */
	while (sz_serial.available() > 0)
	{
		(void)sz_serial.read();
		rx_ignored++;
	}

	digitalWrite(PIN_RS485_DE, HIGH);
	sz_serial.write(sz_command, sizeof(sz_command));
	/* SoftwareSerial::write() este bit-bang blocant, deci ultimul bit de stop a
	 * iesit deja cand se intoarce. Marja acopera timpul de propagare prin
	 * transceiver; fara ea, coborarea lui DE poate trunchia ultimul bit.
	 */
	delayMicroseconds(100);
	digitalWrite(PIN_RS485_DE, LOW);
}

/**
 * @brief Colecteaza un cadru, cu sincronizare pe adresa si functie.
 *
 * La alimentare senzorul emite un banner text ("APP Run..."), lung exact cat un
 * cadru Modbus. Fara filtrul de aici el umple bufferul si consuma o incercare
 * intreaga, iar raspunsul real, care vine imediat dupa, se pierde.
 *
 * @return true daca s-au adunat MODBUS_FRAME_LEN octeti in timpul alocat.
 */
static bool frame_collect(void)
{
	uint32_t t0 = millis();

	rx_buf_pos = 0;
	memset(rx_buf, 0, sizeof(rx_buf));

	while (millis() - t0 < DIST_TIMEOUT_MS)
	{
		if (sz_serial.available() <= 0)
		{
			continue;
		}

		uint8_t c = (uint8_t)sz_serial.read();

		if (rx_buf_pos == 0 && c != MODBUS_SLAVE_ADDR)
		{
			rx_ignored++;
			continue;
		}

		if (rx_buf_pos == 1 && c != MODBUS_FUNC_READ)
		{
			/* Octetul poate fi el insusi inceputul unui cadru valid: pastram
			 * sincronizarea in loc sa o pierdem.
			 */
			rx_ignored++;
			rx_buf_pos = (c == MODBUS_SLAVE_ADDR) ? 1 : 0;
			continue;
		}

		rx_buf[rx_buf_pos++] = c;

		if (rx_buf_pos == MODBUS_FRAME_LEN)
		{
			return true;
		}
	}

	return false;
}

/**
 * @brief Decodeaza cadrul primit.
 *
 * @param[out] cm Distanta in centimetri.
 * @return DIST_OK, DIST_ERR_CRC sau DIST_ERR_RANGE.
 */
static enum dist_status frame_decode(uint16_t *cm)
{
	uint16_t crc;
	uint16_t calc_crc;
	uint16_t value;

	/* Adresa si functia sunt deja garantate de sincronizare; verificarea ramane
	 * ca plasa de siguranta daca aceasta se schimba.
	 */
	if (rx_buf[0] != MODBUS_SLAVE_ADDR || rx_buf[1] != MODBUS_FUNC_READ)
	{
		return DIST_ERR_CRC;
	}

	crc = rx_buf[5] | ((uint16_t)rx_buf[6] << 8);
	calc_crc = modrtu_crc(rx_buf, MODBUS_FRAME_LEN - 2);
	if (crc != calc_crc)
	{
		Serial.print(F("  CRC gresit: primit 0x"));
		Serial.print(crc, HEX);
		Serial.print(F(", calculat 0x"));
		Serial.println(calc_crc, HEX);
		return DIST_ERR_CRC;
	}

	/* 0xFF pe octetul superior: senzorul raporteaza "in afara plajei". */
	if (rx_buf[3] == 0xFF)
	{
		return DIST_ERR_RANGE;
	}

	value = ((uint16_t)rx_buf[3] * 256 + rx_buf[4]) / 10; /* transformam in cm */

	if (value < DIST_MIN_CM || value > DIST_MAX_CM)
	{
		Serial.print(F("  Distanta implauzibila: "));
		Serial.print(value);
		Serial.println(F(" cm"));
		return DIST_ERR_RANGE;
	}

	*cm = value;
	return DIST_OK;
}

enum dist_status dist_sensor_measure(uint16_t *cm)
{
	enum dist_status status = DIST_ERR_NO_REPLY;

	rx_ignored = 0;

	for (uint8_t attempt = 0; attempt < DIST_RETRIES; attempt++)
	{
		request_send();

		if (!frame_collect())
		{
			Serial.print(F("  incercarea "));
			Serial.print(attempt + 1);
			Serial.print(F(": cadru incomplet, "));
			Serial.print(rx_buf_pos);
			Serial.print(F("/7 octeti ("));
			Serial.print(rx_ignored);
			Serial.println(F(" ignorati)"));
			status = DIST_ERR_NO_REPLY;
			continue;
		}

		status = frame_decode(cm);
		if (status == DIST_OK)
		{
			return DIST_OK;
		}
	}

	return status;
}

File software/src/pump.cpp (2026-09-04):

/*
 * Copyright (c) 2026 Popa Ionel, TWM
 *
 * SPDX-License-Identifier: Apache-2.0
 */

#include <Arduino.h>

#include "config.h"
#include "pump.h"

static enum pump_state state;

/* Citiri consecutive care sustin tranzitia curenta. Se reseteaza la orice
 * citire care o contrazice, deci un varf izolat nu comanda releul.
 */
static uint8_t confirmari;

/* Citiri esuate, respectiv reusite, consecutive - pentru intrarea in si iesirea
 * din AVARIE_SENZOR.
 */
static uint8_t esecuri;
static uint8_t reveniri;

static uint32_t t_pornire;

/* Fereastra filtrului median. Elimina citirea singulara aberanta (reflexie
 * parazita, val) fara sa intarzie raspunsul ca o medie alunecatoare.
 */
static uint8_t hist[3];
static bool hist_plina;

const char *pump_state_str(enum pump_state st)
{
	switch (st)
	{
	case POMPA_OPRITA:
		return "OPRITA";
	case POMPA_PORNITA:
		return "PORNITA";
	case AVARIE_SENZOR:
		return "AVARIE_SENZOR";
	case AVARIE_TIMP:
		return "AVARIE_TIMP";
	default:
		return "?";
	}
}

static void releu_set(bool pornit)
{
	digitalWrite(PIN_RELEU, pornit ? RELEU_ACTIV : RELEU_INACTIV);
}

static uint8_t median3(uint8_t nivel)
{
	uint8_t a, b, c;

	if (!hist_plina)
	{
		/* Prima citire valida dupa pornire sau dupa o avarie: umplem fereastra
		 * cu ea, ca sa nu introducem o valoare inventata in mediana.
		 */
		hist[0] = hist[1] = hist[2] = nivel;
		hist_plina = true;
	}
	else
	{
		hist[0] = hist[1];
		hist[1] = hist[2];
		hist[2] = nivel;
	}

	a = hist[0];
	b = hist[1];
	c = hist[2];

	if (a > b)
	{
		uint8_t t = a;
		a = b;
		b = t;
	}
	if (b > c)
	{
		b = c;
	}
	return (a > b) ? a : b;
}

void pump_init(void)
{
	/* Nivelul se scrie inaintea lui pinMode(): altfel pinul ar trece printr-o
	 * stare de iesire cu ultimul continut al registrului PORT, iar pe un releu
	 * activ pe HIGH asta inseamna pompa pornita pentru cateva microsecunde la
	 * fiecare reset.
	 */
	digitalWrite(PIN_RELEU, RELEU_INACTIV);
	pinMode(PIN_RELEU, OUTPUT);
	releu_set(false);

	state = POMPA_OPRITA;
	confirmari = 0;
	esecuri = 0;
	reveniri = 0;
	hist_plina = false;
}

enum pump_state pump_get_state(void)
{
	return state;
}

void pump_update(uint8_t nivel_pct, bool valid)
{
	uint8_t nivel;

	if (!valid)
	{
		reveniri = 0;
		confirmari = 0;

		if (esecuri < 255)
		{
			esecuri++;
		}

		/* AVARIE_TIMP are prioritate: e cu retinere si nu vrem sa fie stearsa
		 * de o avarie care se auto-repara.
		 */
		if (esecuri >= MAX_ESECURI_SENZOR && state != AVARIE_TIMP)
		{
			if (state != AVARIE_SENZOR)
			{
				releu_set(false);
				state = AVARIE_SENZOR;
				hist_plina = false;
			}
		}
		return;
	}

	esecuri = 0;
	nivel = median3(nivel_pct);

	switch (state)
	{
	case AVARIE_TIMP:
		/* Cu retinere: put secat sau senzor blocat. Repornirea automata ar
		 * lasa pompa sa mearga in gol la nesfarsit.
		 */
		releu_set(false);
		break;

	case AVARIE_SENZOR:
		if (++reveniri >= CONFIRMARI_REVENIRE)
		{
			/* Revenim in OPRITA, nu direct in PORNITA: pornirea se
			 * re-evalueaza pe drumul normal, cu confirmari.
			 */
			state = POMPA_OPRITA;
			confirmari = 0;
			reveniri = 0;
		}
		break;

	case POMPA_OPRITA:
		if (nivel <= PRAG_PORNIRE_PCT)
		{
			if (++confirmari >= CONFIRMARI_SCHIMBARE)
			{
				releu_set(true);
				state = POMPA_PORNITA;
				t_pornire = millis();
				confirmari = 0;
			}
		}
		else
		{
			confirmari = 0;
		}
		break;

	case POMPA_PORNITA:
		if (millis() - t_pornire > MAX_TIMP_UMPLERE_MS)
		{
			releu_set(false);
			state = AVARIE_TIMP;
			confirmari = 0;
			break;
		}

		if (nivel >= PRAG_OPRIRE_PCT)
		{
			if (++confirmari >= CONFIRMARI_SCHIMBARE)
			{
				releu_set(false);
				state = POMPA_OPRITA;
				confirmari = 0;
			}
		}
		else
		{
			confirmari = 0;
		}
		break;
	}
}

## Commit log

2026-09-04 placa si soft comanda pompa umplere bazin cu atmega328
    [comanda_pompa_ A0121A4.kicad_pcb, comanda_pompa_ A0121A4.kicad_pcb_bom.csv, comanda_pompa_ A0121A4.kicad_pcb_positions.csv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]
2026-09-04 module in hardware
    [comanda_pompa_ A0121A4.kicad_pcb, comanda_pompa_ A0121A4.kicad_sch]
